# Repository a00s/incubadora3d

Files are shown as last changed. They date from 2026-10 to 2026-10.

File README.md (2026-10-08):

# Mini incubadora CO₂ — v59

Modelo mecânico para impressão 3D, desenvolvido em CadQuery, com porta articulada,
três gavetas removíveis, reservatório de água e compartimentos de CO₂ e eletrônica.
A versão atual completa a rampa a 45° atrás da base da lingueta, incluindo seu lado externo.
As gavetas usam guias abertas e as lâminas são apoiadas somente por baixo.
Vedação, resistência e funcionamento térmico ainda precisam de validação física.

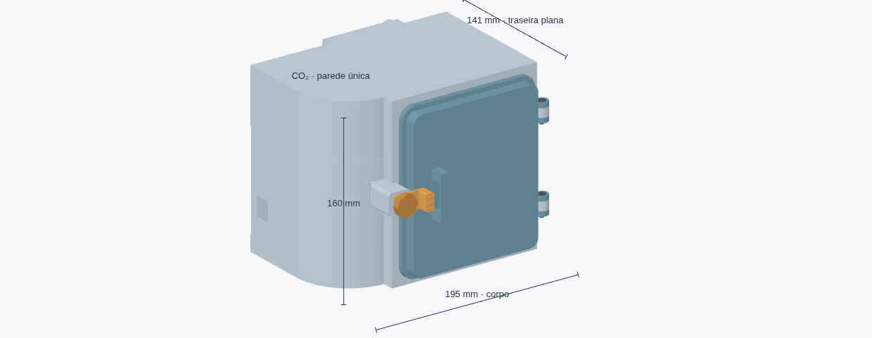
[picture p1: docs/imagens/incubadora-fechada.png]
Incubadora v59 fechada, com porta e fecho central


## Arquivos para visualizar e imprimir

- [Visualizador interativo offline](output/visualizador.html): baixe e abra no navegador.
- [Projeto Creality Print 7.2.1](output/incubadora_CrealityPrint_7.2.1.3mf): 38 peças em 36 bandejas, incluindo molde e contraformas, escala 1:1, sem fatiamento ou G-code.
- [Molde e contraforma do inox](output/v59/ferramental_inox/LEIA_ME.md): macho e duas metades de fechamento, com STL e STEP.
- [STL da carcaça com a traseira na mesa](output/v59/impressao_traseira_na_mesa/corpo_integrado.stl).
- [STL, STEP, amostras e relatórios da v59](output/v59/).
- [Conjunto completo em STEP](output/v59/conjunto.step).
- [Situação técnica e pendências](STATUS.md).

O GitHub não executa o HTML: salve o arquivo localmente para usar os controles.
Os arquivos de versões antigas foram removidos da árvore atual; podem ser recuperados pelo histórico do Git.

## Medidas principais

As medidas estão em milímetros. Largura × altura × profundidade para a câmara e o inox.

| Elemento | Medida |
| --- | --- |
| Carcaça na orientação de montagem, largura × profundidade × altura | 195 × 141 × 160 |
| Carcaça com a traseira na mesa, largura × profundidade da mesa × altura de impressão | 195 × 160 × 141 |
| Câmara rígida interna | 112 × 132 × 111; cantos R6 |
| Caixa inox, dimensão externa de referência | 111 × 131 × 110 |
| Caixa inox, dimensão interna de referência | 110,4 × 130,4 × 109,7 |
| Espessura do inox de referência | 0,3 |
| Gavetas, largura × profundidade × espessura da base | 102,2 × 72 × 3 |
| Passo vertical entre gavetas | 29 |
| Alojamento das lâminas | 76,8 × 26,8; rebaixo de 0,6 |
| Caixinha traseira, largura × altura × profundidade | 70 × 60 × 21 |

A caixa inox e o [molde de referência](output/v59/molde_caixa_inox_referencia.stl)
não constituem um plano de corte de chapa: dobras, raios e acabamento precisam ser
conferidos na fabricação. Os furos de referência do inox alinham as passagens de CO₂ e fios.

## Porta, vedação e acesso

A porta é uma peça rígida, com todo o ressalto interno em V de ponta plana.
O ressalto entra no perfil correspondente do corpo. Uma junta TPU labial
fica encaixada nele; a junta TPU do corpo complementa a vedação.
O manípulo central regula a compressão. A estanqueidade depende do ajuste e de ensaio físico.

Para abrir, afrouxe o manípulo e gire a lingueta central 90° para baixo.
A pega lateral é uma dupla hélice circular real, com duas curvas vistas de frente,
hastes cilíndricas Ø3,2 mm e travessas Ø2,2 mm. Os apoios são curvos e se
alargam gradualmente até a porta, com raio de 1,8 a 4 mm.
A hélice tem raio de 6 mm e uma volta completa ao longo de 36 mm;
o envelope com apoios tem altura de 54 mm, profundidade de 15,2 mm e
projeção de 18,6 mm além da placa. Imprimir com a **frente externa plana na mesa**
e o ressalto interno em V para cima, com suportes externos para a hélice.
O isolamento da porta foi redesenhado para essa posição: 30 canais alongados,
em duas fileiras, com paredes de 2 mm. Os tetos avançam a 45° no sentido +Y
do CAD e fecham pela largura curta de cada canal, com ponte final de 0,4 mm.
A [conferência das rampas](output/v59/door_roof_report.json) e o
[fatiamento de teste deitada](output/v59/door_slice_report.json) estão registrados.
No visualizador, escolha **Impressão da porta · frente para baixo** e mova
**Camada da porta** entre 5,2 e 8 mm para ver os canais fechando.
Os vazados pertencem somente à pega externa: nenhum corte atravessa a porta,
as células de isolamento ou o perímetro de vedação. O canal e as juntas TPU
foram preservados. Ergonomia e estanqueidade dependem de teste físico.
As duas dobradiças usam M4 × 20 escareados, porcas metálicas na porta e buchas de compressão.
Os apoios fixos têm rampas externas a 45° para impressão da carcaça com a traseira na mesa.
Atrás das duas dobradiças e da base da lingueta, as rampas dentro da parede também
fecham a 45°, substituindo os tetos retos sobre as cavidades de isolamento.
A base da lingueta também tem rampa externa, eliminando a face traseira reta que
ainda ficava suspensa. O reforço preserva o volume interno do compartimento de CO₂.

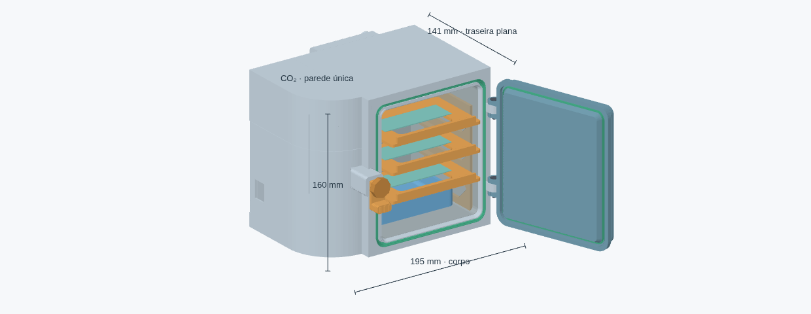
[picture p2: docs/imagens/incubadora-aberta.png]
Porta aberta a 110° e gavetas parcialmente retiradas na v59


O misturador de CO₂ tem teto integrado, com abertura para o sensor.
A tampa lateral removível dá acesso à eletrônica: solte seu M4 × 12 e retire-a para cima.
A entrada de gás recebe mangueira de silicone Ø externo 6,0 em alojamento Ø6,2,
com boca chanfrada Ø6,8 e profundidade de encaixe de 12 mm.
O canal interno de comunicação com a câmara e o furo correspondente no inox têm Ø6,2.
A folga diametral nominal é de 0,2 mm; conferir encaixe e vedação nas amostras OD6.
O canal não bloqueia retorno de umidade.

## Gavetas e lâminas

O suporte removível tem laterais reforçadas e apoios de 6 mm de largura.
As gavetas entram pela frente em guias abertas, com chanfro de entrada de 2 mm
e folga lateral de 0,8 mm por lado. Apoie a gaveta nos dois trilhos e deslize até o batente traseiro.
Não há tampa superior do trilho nem encaixe estreito para alinhar.
Para retirar completamente, puxe a gaveta segurando-a quando ela deixar os apoios.

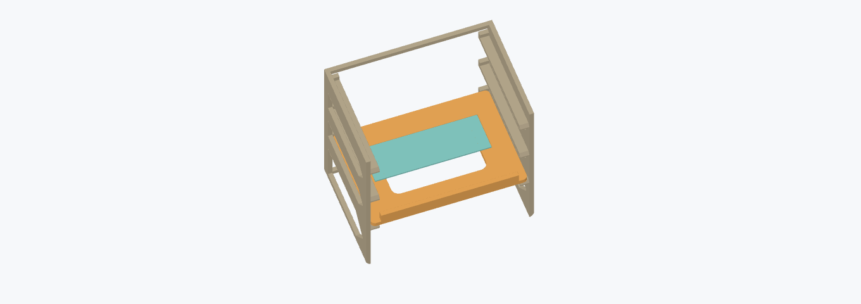
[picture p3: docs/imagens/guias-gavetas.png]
Suporte reforçado com guias abertas e uma gaveta assentada


A lâmina fica num rebaixo de 0,6 mm na própria base. O apoio é somente inferior;
as bordas do rebaixo limitam o deslocamento horizontal. Coloque e retire a lâmina
por cima. Não há presilhas, lingueta ou material sobre sua área.
O alojamento aberto permite levantar a lâmina e não a retém se a gaveta for invertida.

O desenho foi conferido para lâminas de 76 × 26 e 75 × 25, com espessuras de 0,9 a 1,2.
A referência visual mede 76 × 26 × 1. A área central da gaveta permanece vazada.

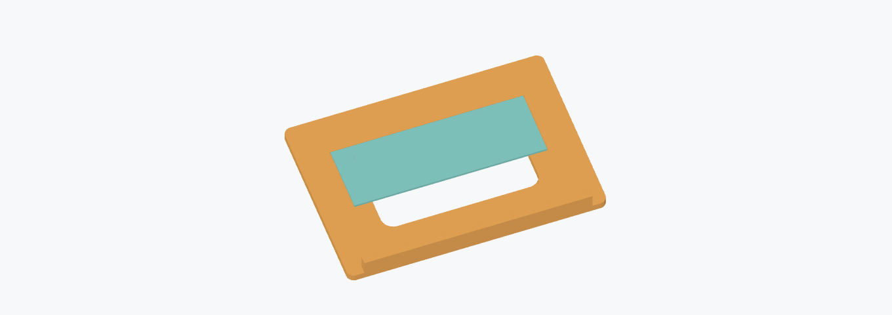
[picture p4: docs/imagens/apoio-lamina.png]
Lâmina apoiada por baixo no rebaixo da gaveta, totalmente livre por cima


## Caixinha traseira e passagens

A caixinha de 70 × 60 × 21 acomoda a sobra dos fios e tem conector lateral Ø8.
As bordas superior e inferior que tocam a incubadora são retas.
A fixação usa dois M4 × 12, com aproximadamente 4 mm de engate no corpo.
Os pilotos são cegos, dentro de apoios maciços Ø16: há 5,6 mm de material atrás
do piloto e 6,25 mm nas laterais. A parede quente de 4 mm permanece contínua sob os apoios.

As passagens de fios usam buchas TPU. Montagem dos fios, compressão das buchas,
retenção dos parafusos e vedação precisam ser conferidas com os componentes reais.
Teste primeiro a [amostra da fixação M4](output/v59/amostra_caixinha_fixacao_M4.stl).

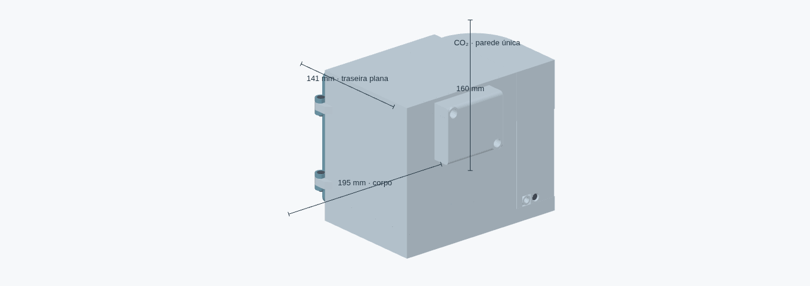
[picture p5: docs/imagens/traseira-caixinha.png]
Vista traseira com caixinha de fios e fixações da v59


## Impressão

A orientação da **carcaça** é com a traseira apoiada na mesa.
Use o STL indicado acima ou a bandeja da carcaça no projeto Creality Print.
A camada de isolamento tem 23 cavidades alongadas, faces de 2 mm e fechamento a 45°,
com ponte final nominal de 0,4 mm. A parede da câmara tem 4 mm.
Os furos e as fixações mantêm reforços locais maciços.

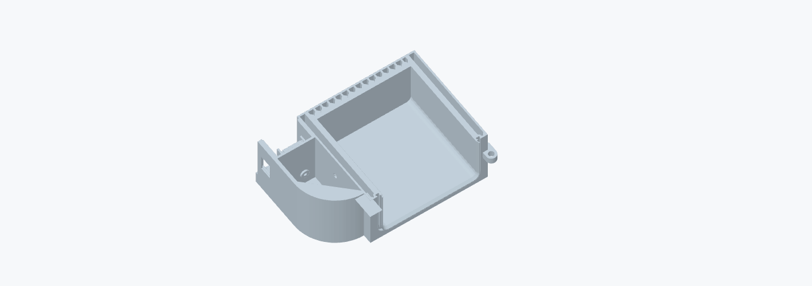
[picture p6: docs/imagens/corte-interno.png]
Corte da carcaça mostrando cavidades alongadas e canais na parede traseira


Materiais previstos no desenho: PC para peças rígidas, TPU 95A para vedações e
inox de 0,3 mm para o revestimento. O 3MF referencia os perfis genéricos
PC/TPU e o processo padrão da K1C com bico de 0,4 mm, sem configurações
personalizadas de filamento ou velocidades por peça. Selecione sua configuração
padrão no Creality Print e ajuste a temperatura conforme o filamento utilizado.
As juntas estão atribuídas ao TPU; imprima cada bandeja com o material correspondente.
O projeto não contém um processo de impressão validado.
STL e STEP contêm geometria; as configurações ficam no projeto 3MF.

Antes de imprimir, confira na prévia de camadas:

- Ausência de suporte preso dentro das cavidades fechadas da carcaça.
- Perímetros e continuidade de material ao redor de furos e vedações.
- Pontes, encaixes, roscas e pequenos detalhes com os parâmetros escolhidos.
- Orientação da porta: ainda não foi definida nem validada.

O suporte das gavetas foi desenhado para a traseira na mesa; as janelas fecham a 45°.
As gavetas têm base plana. As orientações das demais peças no projeto devem ser revisadas.
Imprima as amostras de encaixe e vedação antes de comprometer a carcaça inteira.

## Visualizador

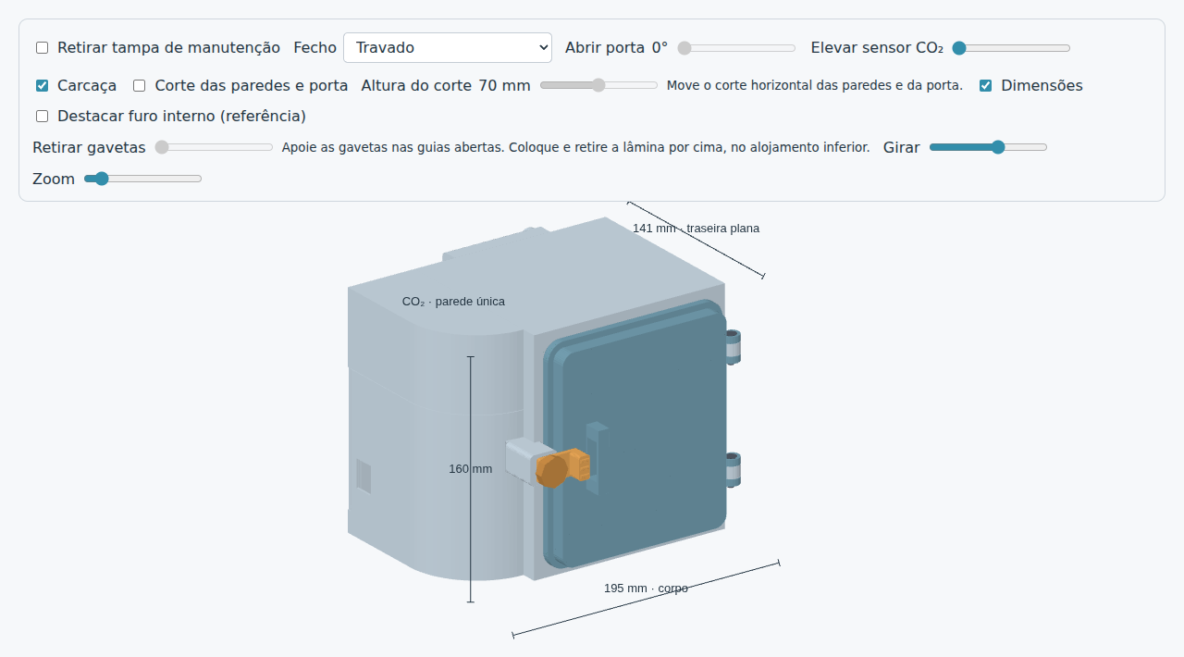
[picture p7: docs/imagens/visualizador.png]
Controles atuais do visualizador da v59


- Arraste o modelo para girar e use **Zoom** para aproximar.
- Selecione **Fecho → Afrouxado e girado 90°** para abrir a porta.
- A retirada das gavetas é liberada no visualizador a partir de 90° de abertura.
- Use **Corte das paredes e porta** e **Altura do corte** para inspecionar as cavidades.
- Em **Peças**, marque componentes ou use **Isolar**.

Os controles mostram a geometria; não substituem testes físicos.

## Gerar os arquivos

Na pasta do repositório:

```bash
python3 -m venv .venv
.venv/bin/python -m pip install -r requirements.txt
.venv/bin/python cad/model.py
.venv/bin/python cad/check_k1c.py
.venv/bin/python cad/build_viewer.py
.venv/bin/python cad/build_creality_project.py --version v59
.venv/bin/python cad/check_creality_project.py --version v59
```

O gerador confere sólidos, interferências e movimentos específicos da porta,
gavetas e lâminas. Os testes adicionais de movimento/roscas são opcionais:

```bash
.venv/bin/python cad/model.py --check-movements
```

Para servir o visualizador na rede local:

```bash
mkdir -p /tmp/incubadora3d-viewer
cp output/visualizador.html /tmp/incubadora3d-viewer/index.html
python3 -m http.server 8081 --bind 0.0.0.0 --directory /tmp/incubadora3d-viewer
```

Acesse `http://IP_DO_SERVIDOR:8081/` com a porta acessível na rede.

## Validação disponível

A v59 passou em 60 pares rígidos sem colisões. O projeto contém 36 bandejas em escala 1:1;
as malhas cabem na K1C com margem de 5 mm. A leitura nativa do Creality Print 7.2.1
terminou com 36 malhas manifold. Gavetas foram conferidas em sete posições de extração;
a área acima das lâminas está livre em um envelope vertical contínuo de 40 mm.

Relatórios: [tetos dos apoios](output/v59/internal_mount_roof_report.json),
[geometria e colisões](output/v59/clash_report.json),
[gavetas e lâminas](output/v59/tray_retention_report.json) e
[projeto Creality](output/v59/projeto_creality_verificacao.json).
Não há fatiamento, ensaio de estanqueidade ou validação operacional.

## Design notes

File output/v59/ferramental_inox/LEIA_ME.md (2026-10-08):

# Molde e contraforma para inox de 0,3 mm

O macho reproduz o interior do revestimento existente e é maciço no CAD.
As contraformas têm paredes de 24 mm, nervuras externas de 12 mm e fechamento
traseiro de 12 mm para apoiar o fundo e travar as laterais. As duas contraformas
fecham por cima e por baixo dele, apoiando os quatro cantos longitudinais.
A cavidade reserva 0,3 mm para a chapa e mais 0,15 mm por face para ajuste.
Raio do macho: 5,2 mm; raio da cavidade: 5,65 mm; comprimento útil: 109,7 mm.

## Arquivos para imprimir

- [Molde interno — macho](molde_caixa_inox_referencia.stl).
- [Contraforma inferior](contraforma_inox_inferior.stl).
- [Contraforma superior](contraforma_inox_superior.stl).

Há um STEP de cada peça nesta pasta para usinagem ou ajustes.
Os STL já estão com uma extremidade plana na mesa, Z mínimo zero.
As três peças cabem individualmente na K1C com margem de 5 mm.
O projeto completo `output/incubadora_CrealityPrint_7.2.1.3mf` inclui todas
as ferramentas: macho na bandeja 10, contraforma inferior na 35 e superior na 36.
As duas últimas compartilham espaço com amostras pequenas de PC, sem sobreposição.
O projeto possui 38 peças em 36 bandejas.
A escolha de paredes, preenchimento e material deve considerar o esforço aplicado;
a resistência das ferramentas impressas ainda não foi ensaiada.

## Uso

1. Pré-dobre as laterais da chapa ao redor do macho. O ferramental serve para
   acertar as dobras e os raios de uma chapa já pré-formada.
2. Apoie a contraforma inferior numa placa plana e rígida. Coloque o macho
   com o inox dentro dela e encaixe a contraforma superior.
3. Alinhe os quatro furos Ø6,6 mm. Eles aceitam hastes ou parafusos M6;
   a distância total entre faces externas fechadas é 179,3 mm.
   Se usar parafusos, reserve comprimento adicional para placas, arruelas e porcas.
4. Distribua o aperto com outra placa rígida por cima e feche gradualmente,
   alternando os lados. As faces de encontro das contraformas limitam o fechamento.
5. Abra as metades e retire o macho pela frente. Faça primeiro um ensaio com
   retalho do mesmo inox para avaliar acabamento, folga e retorno elástico.

## Marcação e furação do inox

As guias passantes da contraforma têm Ø2,5 mm. No macho, os mesmos eixos têm
pilotos cegos Ø2,5 × 3 mm. Use-os com o ferramental **fechado**, para marcar
ou iniciar os furos sem deslocar a chapa. Retire a chapa para ampliar ao diâmetro
final e remover rebarbas; não perfure o macho além dos pilotos cegos.

| Furo | Centro no CAD (mm) | Direção | Diâmetro final |
| --- | --- | --- | --- |
| Entrada CO₂ | X=4,5; Y=60; Z=34 | lateral, eixo X | 6,2 mm |
| Acesso lateral | X=4,5; Y=90; Z=127,5 | lateral, eixo X | 14 mm |
| Acesso traseiro | X=60; Y=110; Z=116 | fundo, eixo Y | 14 mm |

Os centros correspondem às três aberturas do revestimento atual. Os furos
Ø6,6 mm das abas são de alinhamento M6 e não são furos a transferir ao inox.

O conjunto conforma as quatro dobras ao longo da profundidade da caixa.
**O fundo, os recortes e as emendas não são formados por essas peças.**
O revestimento CAD continua sendo uma referência de montagem, não um desenho
planificado de corte e solda. A folga adicional não foi compensada por simulação
de retorno elástico, nem foi calculada uma força de prensa.

## Visualizador

Abra [visualizador.html](../../visualizador.html) e escolha
**Visualizar → Molde e contraforma do inox**. O controle **Abrir contraforma**
afasta cada metade de 0 a 80 mm. Na lista de peças é possível ocultar o macho,
o inox ou cada metade para inspecionar o encaixe. A opção **Destacar centros
dos furos no ferramental** mostra as posições e os diâmetros finais no inox.

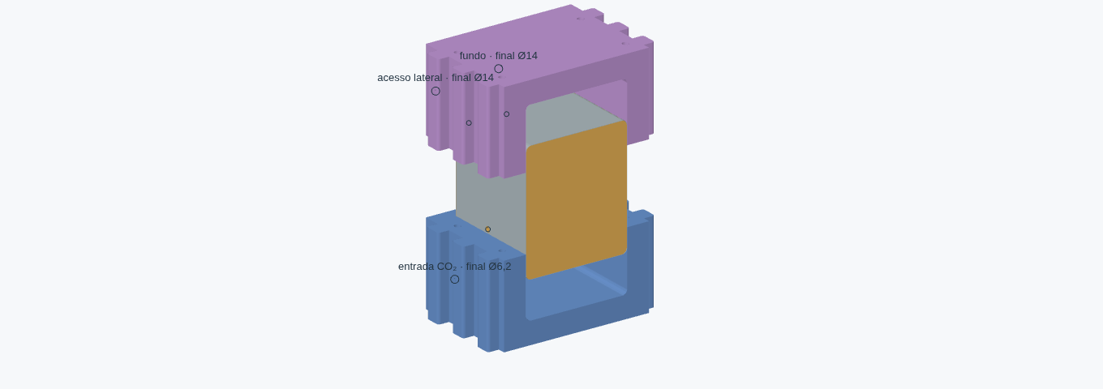
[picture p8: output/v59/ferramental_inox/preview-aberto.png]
Conjunto aberto


## Regeneração e verificações

Execute `python cad/forming_tools.py` no ambiente com CadQuery e depois
`python cad/build_viewer.py`. O gerador principal `cad/model.py` também exporta
o ferramental. `python cad/pack_forming_tools.py` atualiza o ferramental
no 3MF salvo pelo usuário, preservando suas configurações. Execute
`python cad/check_complete_project.py` para verificar esse arquivo.
[verificacao.json](verificacao.json) registra os limites e as
verificações de sólidos, interferências e abertura.

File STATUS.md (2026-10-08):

# Estado atual — v59

Arquivos atuais em [output/v59](output/v59/), com visualizador e projeto Creality Print
na raiz de `output/`. A árvore atual mantém somente esta versão; revisões anteriores
estão no histórico do Git. O [manual ilustrado](README.md) descreve o desenho atual.

## Configuração

- Carcaça integrada, impressão com traseira Y125 na mesa, construção na direção −Y.
- Câmara 112 × 132 × 111 mm; parede quente de 4 mm; inox de referência 0,3 mm.
- Isolamento com 23 cavidades alongadas, fechamentos a 45° e ponte nominal de 0,4 mm.
- Porta monolítica com ressalto inteiro em V, junta TPU labial retida e junta secundária no corpo.
- Pega externa em dupla hélice circular real, duas curvas, raio de 6 mm,
  volta completa em 36 mm, hastes Ø3,2 mm e travessas Ø2,2 mm.
  Envelope: altura 54 mm, profundidade 15,2 mm e projeção 18,6 mm além da placa.
  Apoios curvos alargam de R1,8 para R4 junto à porta.
  Frente externa plana Y=-16 na mesa, ressalto V para cima. Isolamento redesenhado: 30 canais em duas fileiras, paredes e nervura central de 2 mm, tetos de 45° fechando em +Y com ponte final de 0,4 mm. Revisar suportes externos na hélice. Nenhum corte na porta ou canal TPU.
  O 3MF salvo pelo usuário recebeu a porta DNA, preservando configurações e demais malhas; validação física de gás pendente.
- Fecho central; lingueta liberando a abertura quando girada 90° após afrouxar o manípulo.
- Duas dobradiças M4 × 20 escareadas, porcas metálicas na porta e apoios externos a 45°.
- Rampas internas a 45° nas cavidades atrás das dobradiças e da base da lingueta.
- Rampa externa da lingueta elimina a face plana remanescente; cavidade CO₂ preservada.
- Auditoria final dos apoios inclui ambos os lados da base da lingueta e das dobradiças.
- Suporte removível reforçado, guias abertas, apoio de 6 mm e folga lateral de 0,8 mm por lado.
- Gavetas com base de 3 mm e rebaixo de lâmina de 0,6 mm; nenhum elemento sobre a lâmina.
- Lâminas conferidas: 76 × 26 e 75 × 25 mm, espessuras 0,9, 1 e 1,2 mm.
- Caixinha traseira 70 × 60 × 21 mm, dois M4 × 12 com engate de 4 mm em apoios cegos maciços.
- Mangueira CO₂ Ø6 mm: entrada e passagem interna Ø6,2 mm, boca Ø6,8 mm e furo do inox Ø6,2 mm; encaixe e vedação física pendentes.
- Misturador CO₂ com teto integrado e abertura do sensor; eletrônica acessível pela tampa lateral.

- Ferramental inox: macho maciço com pilotos cegos e contraformas superior/inferior de 24 mm, nervuras de 12 mm e apoio traseiro. Guias Ø2,5 mm para os três furos do inox; chapa 0,3 mm + folga 0,15 mm por face. Modo próprio no visualizador.

## Validação

- Porta deitada: todas as cavidades CAD e tetos centrais do STL auditados para +Y; rampas de 45°, ponte final ≤0,4 mm e fechamento transversal conferidos. Fatiamento da bandeja 2 no Creality Print 7.2.1: saída 0, sem avisos, altura 19 mm e 99 camadas. Teste separado com brim de 5 mm e suporte a partir da mesa; 18.745 pontos médios de segmentos de suporte conferidos, nenhum dentro das cavidades. Sem ensaio físico.

- Ferramental: três sólidos válidos, sem interseção com o inox; abertura em Z de 0 a 80 mm conferida e visualizador testado em WebGL. Força e retorno elástico pendentes de ensaio físico.
- Corpo único e peças válidas; 59 pares rígidos sem colisão após remover o puxador.
- Faces finais dos tetos auditadas nas duas dobradiças e no fecho: rampas a 45°, pontes restantes ≤0,4 mm.
- Amostra da dobradiça recortada da parede oca real, com ambas as rampas.
- Porta, lingueta, inserção do inox e retirada da caixinha conferidas geometricamente.
- Extração das gavetas a 0, 5, 15, 30, 50, 72 e 80 mm com porta a 110°.
- Apoio inferior e limites laterais das lâminas conferidos; envelope superior de 40 mm livre.
- 38 peças no 3MF completo, compatíveis com a K1C e margem de 5 mm. Macho na bandeja 10 e contraformas nas 35/36, compartilhadas com amostras PC; pelo menos 5 mm entre peças.
- 3MF principal e da v59 atualizados com a porta DNA; ZIP/XML, malha fechada, escala 1:1 e limites K1C conferidos. Abertura nativa e fatiamento da atualização pendentes.
- 3MF com 38 peças em 36 bandejas em escala 1:1, sem G-code; leitura atual das 38 malhas manifold no CLI Creality Print 7.2.1, saída 0, com `--allow-newer-file` para preservar o projeto principal salvo pelo usuário em 7.3. Sem fatiamento.
- Visualizador regenerado com passagem Ø6,2; teste WebGL e controles anterior ao ajuste CO₂. Imagens gerais do manual correspondem à v59.

Relatórios em [output/v59](output/v59/). Os ensaios amplos de roscas/movimento continuam
opcionais em `cad/model.py --check-movements`. TPU com compressão intencional é excluído
da auditoria rígida. As verificações não simulam deformação, resistência ou vazamento.

## Pendências

- 3MF com referências aos perfis genéricos PC/TPU e processo padrão; sem ajustes personalizados de filamento ou velocidades. Selecionar o perfil padrão e ajustar a temperatura no fatiador; sem validação física.
- Fatiamento, calibração dos parâmetros de PC/TPU e ausência de suporte preso nas cavidades fechadas.
- Impressão física da porta com a frente na mesa, suportes externos e testes dos encaixes, roscas e guias.
- Estanqueidade da porta, passagens de fios, conexão de gás e superfícies impressas.
- Ajuste e fabricação da caixa inox; o modelo de referência não é plano de corte de chapa.
- Medidas finais dos conectores, posicionamento do aquecedor, fios e suporte do sensor.
- Desempenho térmico/CO₂, condensação, limpeza e funcionamento operacional.

O alojamento das lâminas é aberto: limita deslizamento enquanto assentadas, mas permite
retirada vertical e não as segura em uma gaveta invertida. Sem validação física ou operacional.

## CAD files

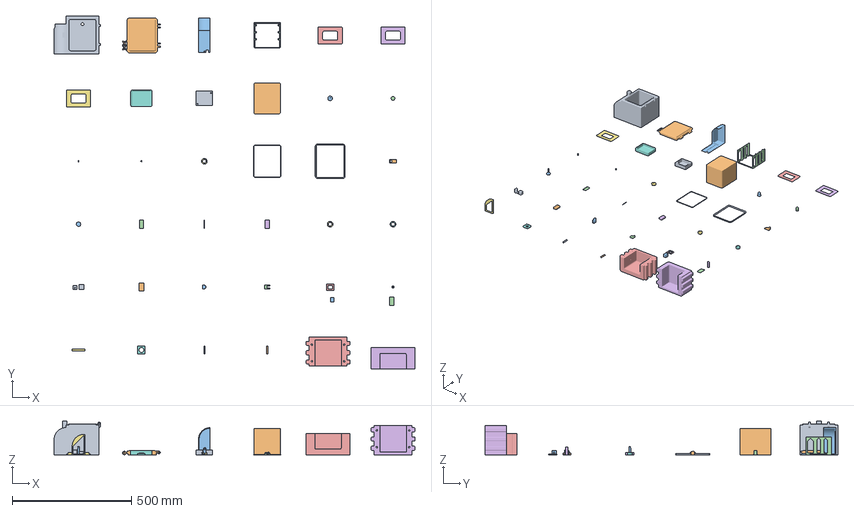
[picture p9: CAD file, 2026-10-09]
output/incubadora_CrealityPrint_7.2.1.3mf
1514.0 x 1481.5 x 141.0 mm
corpo_integrado
porta_articulada
tampa_manutencao_CO2_eletronica
suporte_gavetas_removivel
bandeja_1
bandeja_2
bandeja_3
reservatorio_agua
caixinha_encaixe_aquecedor
molde_caixa_inox_referencia
TPU_passagem_aquecedor
TPU_passagem_sensor
bucha_dobradica_102
bucha_dobradica_22
bucha_sensor_TPU
junta_V_porta_TPU
junta_porta
lingueta_fecho_70
manipulo_fecho_70
amostra_V_assento_corpo
amostra_V_porta_TPU
amostra_V_porta_rigida
amostra_bucha_sensor_TPU_15.3
amostra_bucha_sensor_TPU_15.5
amostra_caixinha_fixacao_M4
amostra_canal_rigido
amostra_dobradica_base_M4x20
amostra_dobradica_porta_M4x20
amostra_encaixe_RJ45
amostra_entrada_CO2_mangueira_OD6
amostra_fechamento_CO2_45graus_PC
amostra_furo_sensor_integrado
amostra_junta_TPU
amostra_junta_TPU_labios_0p8
amostra_passagem_interna_CO2_OD6
amostra_pressao_junta
contraforma_inox_inferior
contraforma_inox_superior

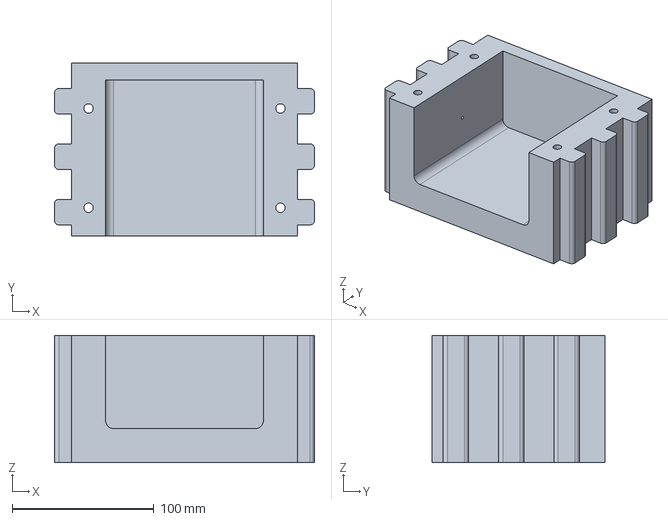
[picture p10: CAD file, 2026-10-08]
output/v59/ferramental_inox/contraforma_inox_inferior.step
183.3 x 122.2 x 89.7 mm

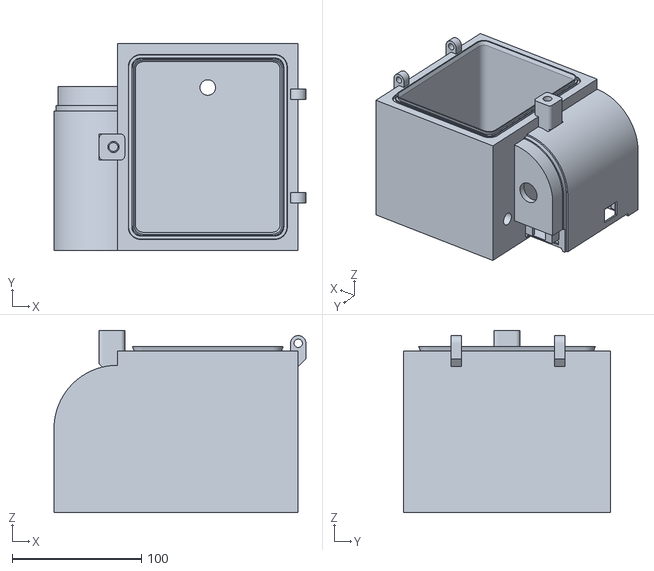
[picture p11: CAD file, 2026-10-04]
output/v59/impressao_traseira_na_mesa/corpo_integrado.stl
195.0 x 160.0 x 141.0

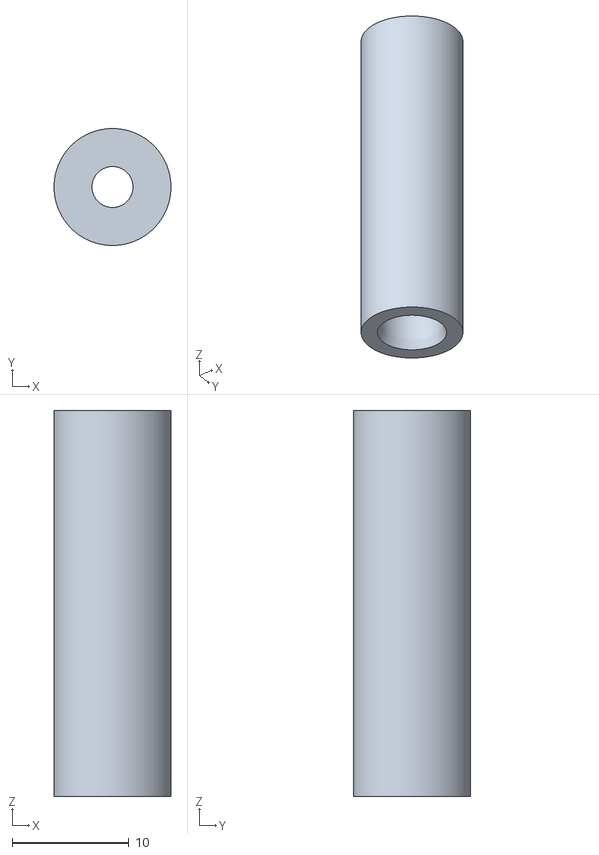
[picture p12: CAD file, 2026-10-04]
output/v59/k1c_posicionados/amostra_entrada_CO2_mangueira_OD6.stl
10.0 x 10.00 x 33.0

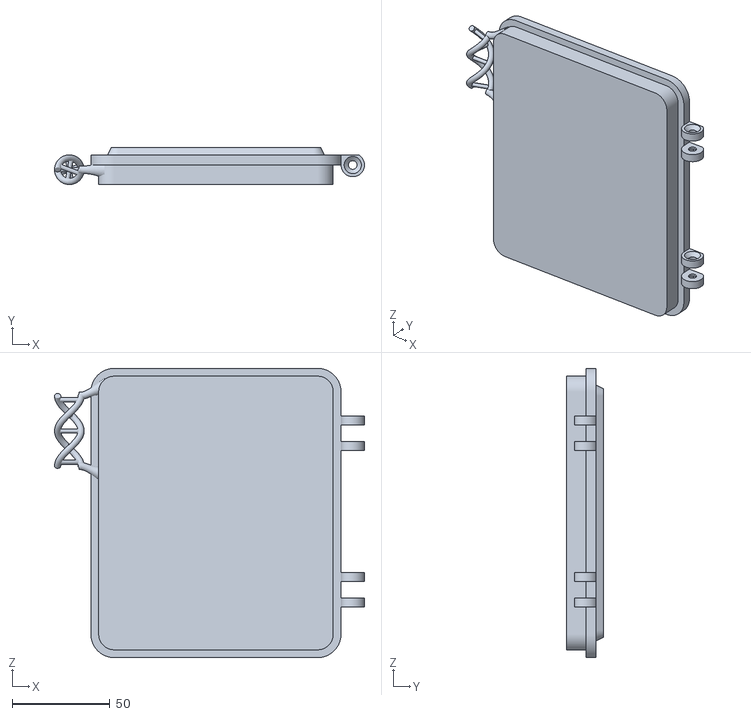
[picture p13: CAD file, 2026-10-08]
output/v59/porta_articulada.stl
158.6 x 19.0 x 148.0

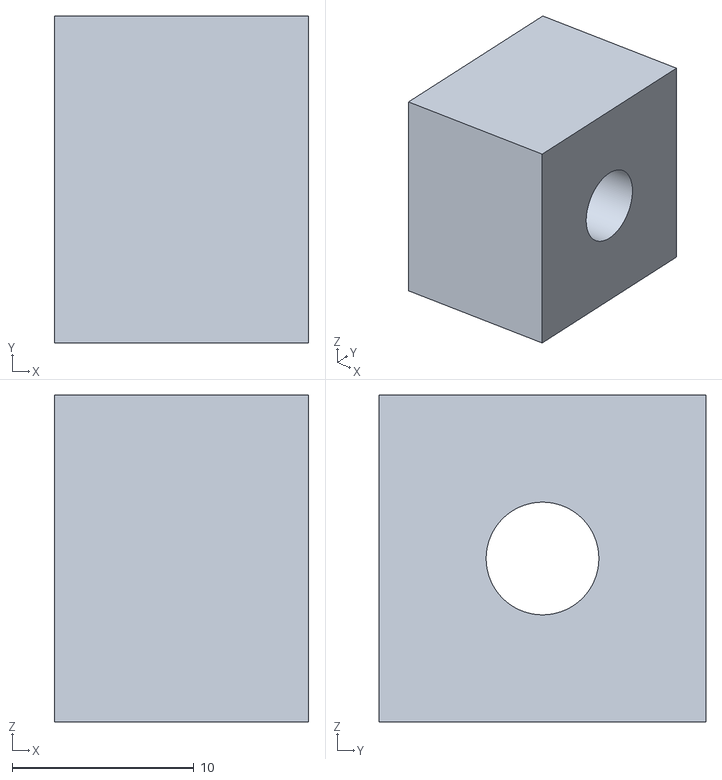
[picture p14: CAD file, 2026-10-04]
output/v59/k1c_posicionados/amostra_passagem_interna_CO2_OD6.stl
14.0 x 18.0 x 18.0

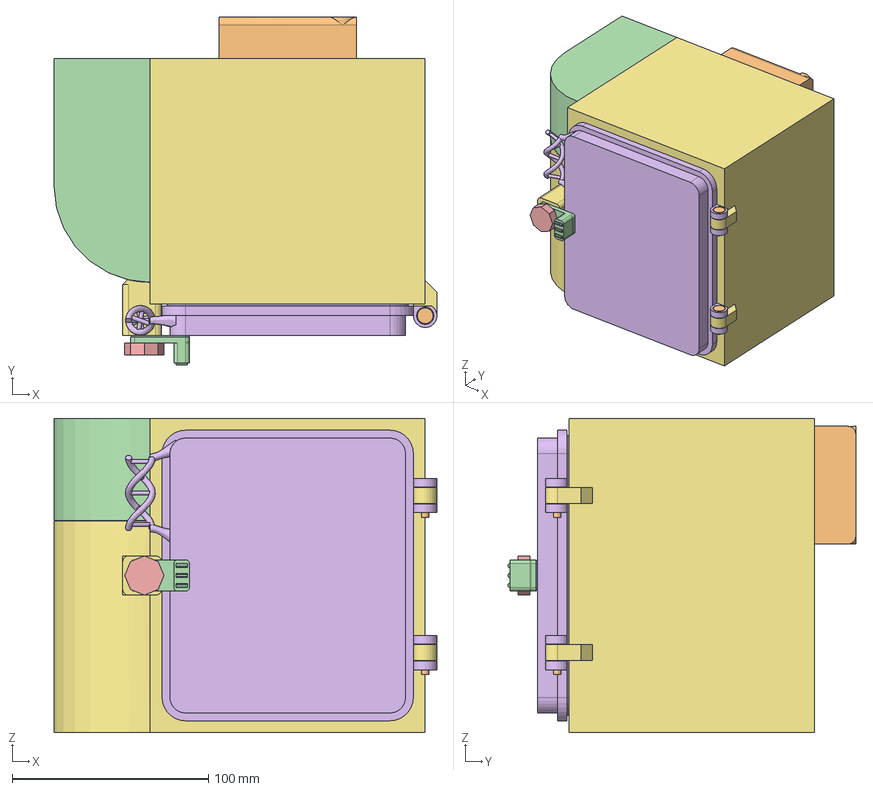
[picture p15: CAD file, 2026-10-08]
output/v59/conjunto.step
195.0 x 177.0 x 160.0 mm

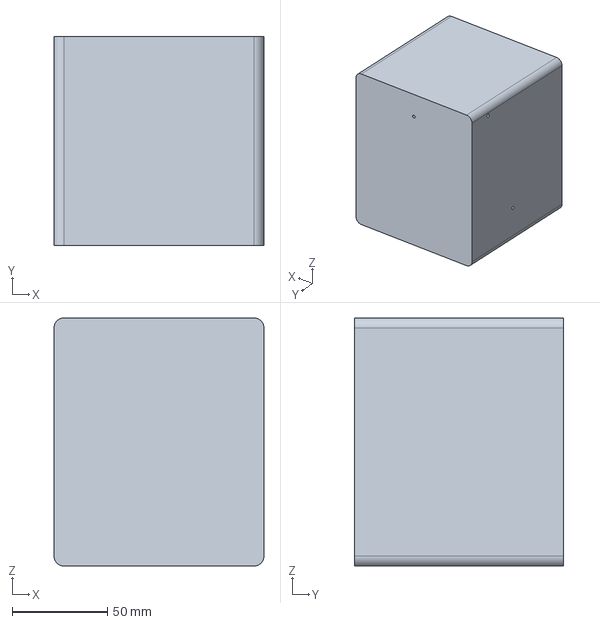
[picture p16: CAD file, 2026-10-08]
output/v59/ferramental_inox/molde_caixa_inox_referencia.step
110.4 x 109.7 x 130.4 mm

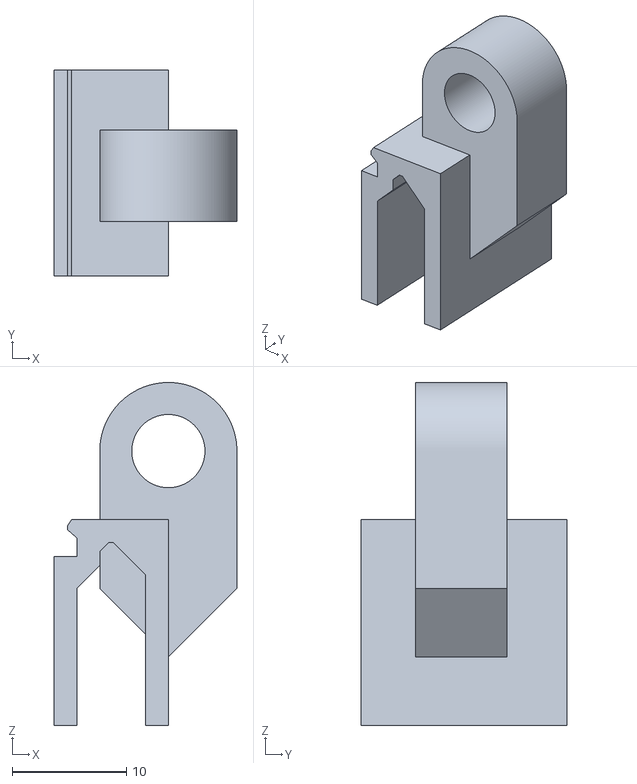
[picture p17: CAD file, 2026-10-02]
output/v59/k1c_posicionados/amostra_dobradica_base_M4x20.stl
16.0 x 18.0 x 30.0

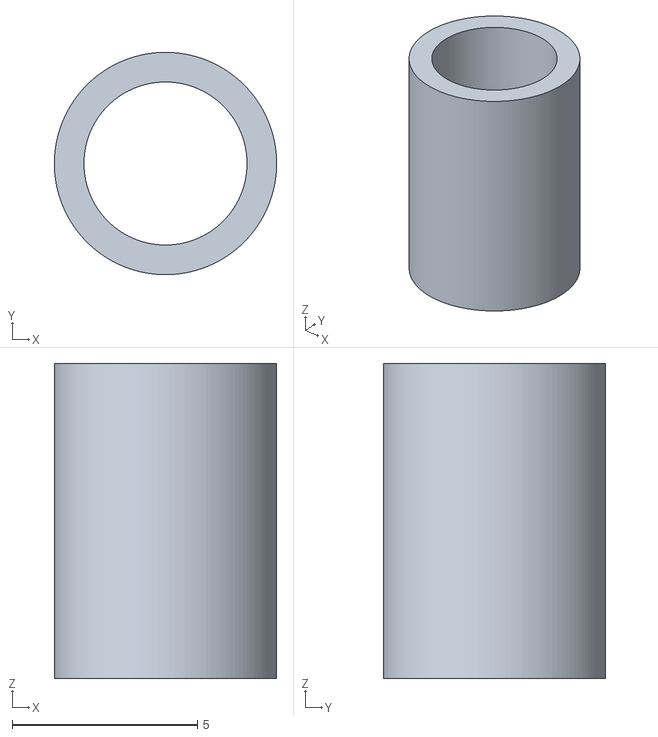
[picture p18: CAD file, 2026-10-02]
output/v59/k1c_posicionados/bucha_dobradica_22.stl
6.00 x 6.00 x 8.50

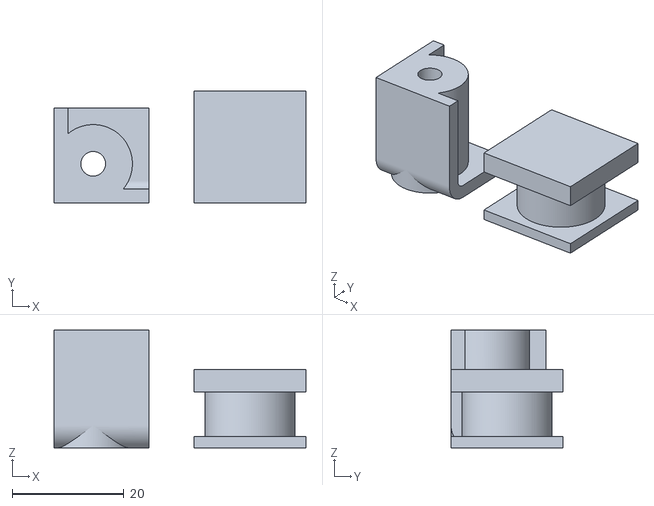
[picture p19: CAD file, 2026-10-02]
output/v59/k1c_posicionados/amostra_caixinha_fixacao_M4.stl
45.0 x 20.0 x 21.0

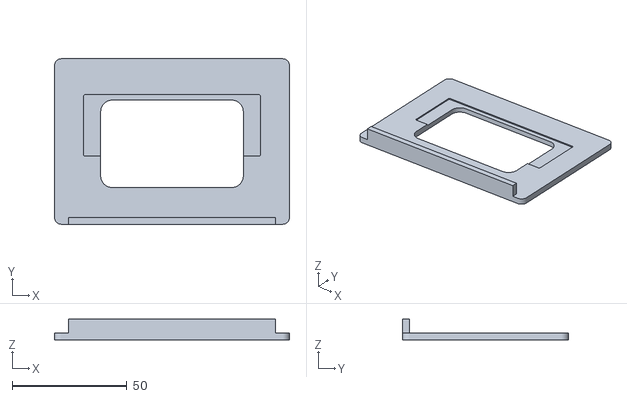
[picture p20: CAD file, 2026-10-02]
output/v59/k1c_posicionados/bandeja_2.stl
102.2 x 72.0 x 9.00

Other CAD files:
output/v59/ferramental_inox/contraforma_inox_superior.step
output/v59/incubadora_v59_CrealityPrint_7.2.1.3mf
output/v59/k1c_posicionados/corpo_integrado.stl
output/v59/molde_caixa_inox_referencia.step
output/v59/corpo_integrado.stl
output/v59/amostra_passagem_interna_CO2_OD6.stl
output/v59/TPU_passagem_aquecedor.stl
output/v59/TPU_passagem_sensor.stl
output/v59/amostra_V_assento_corpo.stl
output/v59/amostra_V_porta_TPU.stl
output/v59/amostra_V_porta_rigida.stl
output/v59/amostra_bucha_sensor_TPU_15.3.stl
output/v59/amostra_bucha_sensor_TPU_15.5.stl
output/v59/amostra_caixinha_fixacao_M4.stl
output/v59/amostra_canal_rigido.stl
output/v59/amostra_dobradica_base_M4x20.stl
output/v59/amostra_dobradica_porta_M4x20.stl
output/v59/amostra_encaixe_RJ45.stl
output/v59/amostra_entrada_CO2_mangueira_OD6.stl
output/v59/amostra_fechamento_CO2_45graus_PC.stl
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

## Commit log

2026-09-21 Atualiza design da incubadora v28 e visualizador
    [TPU_passagem_aquecedor.stl, TPU_passagem_sensor.stl, amostra_bucha_sensor_TPU_15.3.stl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]
2026-09-21 Fecha cantos frontais e adiciona corte ajustável no visualizador v29
    [TPU_passagem_aquecedor.stl, TPU_passagem_sensor.stl, amostra_bucha_sensor_TPU_15.3.stl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]
2026-09-21 Limita rosca do manípulo à ponta junto à porca
    [TPU_passagem_aquecedor.stl, TPU_passagem_sensor.stl, amostra_bucha_sensor_TPU_15.3.stl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]
2026-09-21 Integra roscas do fecho e tampa CO2 à base e amplia haste lisa
    [TPU_passagem_aquecedor.stl, TPU_passagem_sensor.stl, amostra_bucha_sensor_TPU_15.3.stl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]
2026-09-21 Nivela traseira e adiciona pega e contato chanfrado na lingueta
    [TPU_passagem_aquecedor.stl, TPU_passagem_sensor.stl, amostra_bucha_sensor_TPU_15.3.stl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]
2026-10-02 Atualiza incubadora ate v57 com vedacao e gavetas abertas
    [TPU_passagem_aquecedor.stl, TPU_passagem_sensor.stl, amostra_U_borda_corpo.stl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]
2026-10-02 Atualiza manual ilustrado e mantem somente a versao v57
    [TPU_passagem_aquecedor.stl, TPU_passagem_aquecedor_A.stl, TPU_passagem_aquecedor_B.stl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]
2026-10-02 Corrige tetos internos das dobradicas e do fecho na v58
    [TPU_passagem_aquecedor.stl, TPU_passagem_sensor.stl, amostra_V_assento_corpo.stl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]
2026-10-02 Corrige teto externo da base da lingueta com rampa a 45 graus (v59)
    [TPU_passagem_aquecedor.stl, TPU_passagem_sensor.stl, amostra_V_assento_corpo.stl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]
2026-10-03 Configura perfil CC3D PC conforme etiqueta do rolo
    [incubadora_CrealityPrint_7.2.1.3mf, incubadora_v59_CrealityPrint_7.2.1.3mf]
2026-10-04 Ajusta passagens CO2 para tubo de 6 mm e remove perfil personalizado
    [amostra_entrada_CO2_mangueira_OD5p8.stl, amostra_entrada_CO2_mangueira_OD6.stl, amostra_passagem_interna_CO2_OD5p8.stl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]
2026-10-07 Redesenha puxador da porta com dupla helice de DNA e apoios curvos
    [conjunto.step, porta_articulada.stl]
2026-10-08 Atualiza projetos 3MF com porta de puxador DNA
    [incubadora_CrealityPrint_7.2.1.3mf, incubadora_v59_CrealityPrint_7.2.1.3mf]
2026-10-08 Adiciona contraforma bipartida do inox e modo de ferramental no visualizador
    [contraforma_inox_inferior.step, contraforma_inox_inferior.stl, contraforma_inox_superior.step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]
2026-10-08 Reforca ferramental inox, adiciona guias dos furos e inclui contraformas no 3MF completo
    [contraforma_inox_inferior.step, contraforma_inox_inferior.stl, contraforma_inox_superior.step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]
2026-10-08 Corrige orientacao da porta nos projetos 3MF com face externa na mesa
    [incubadora_CrealityPrint_7.2.1.3mf, incubadora_v59_CrealityPrint_7.2.1.3mf]
2026-10-08 Orienta porta em pe conforme rampas internas e valida fatiamento
    [incubadora_CrealityPrint_7.2.1.3mf, incubadora_v59_CrealityPrint_7.2.1.3mf]
2026-10-08 Redesenha canais internos da porta para imprimir com a frente na mesa
    [conjunto.step, incubadora_CrealityPrint_7.2.1.3mf, incubadora_v59_CrealityPrint_7.2.1.3mf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]
2026-10-11 Adiciona fundo interno de 5 mm para conter laterais do inox
2026-10-11 Adiciona moldura frontal removível para apoio e limpeza do inox
2026-10-11 Alarga apoios das gavetas de 6 para 10 mm por lado
2026-10-11 Simplifica centro do suporte e flexibiliza bucha TPU do sensor
2026-10-12 Cria rolhas TPU labiais bipartidas para fios do aquecedor e sensor
2026-10-12 Amplia furo lateral do plugue do aquecedor para 10,68 mm
2026-10-12 Ajusta bucha do sensor para TPU 85A e elimina labios suspensos
2026-10-14 Adapta junta removivel da porta e rolhas para eSUN TPU-LW
2026-10-14 Aumenta junta da porta para tubo oco com lado da dobradica mais baixo
2026-10-15 Add Arduino build workflow and refresh incubator UI
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2026-10-15 Reduz bulbo junto a dobradica e ajusta TPU-LW para 270C
2026-10-15 Migra todas as vedacoes e amostras TPU para eSUN TPU-LW
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2026-10-15 Restore animated indicators and remove stale sensor check
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2026-10-15 Record fan activation and updated CO2 loss rate
2026-10-15 Tighten heater cycling near 37C and record baseline
2026-10-15 Record preliminary loose sensor-ring leak sample
2026-10-15 Refine loose sensor-ring leak comparison
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2026-10-15 Adiciona bulbo oco inferior a bucha CO2 conforme sensor medido
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2026-10-15 Aperta canais dos tres fios do sensor para TPU-LW
2026-10-15 Configura rolha dos tres fios com 30% de preenchimento giroidal
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2026-10-15 Record CO2 decay after water and heat changes
2026-10-15 Redesenha rolha de tres fios como berco com labios e tampa de compressao
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2026-10-15 Alterna painel com gráfico e ajusta doses de CO2
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2026-10-15 Tighten incubator temperature control band
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2026-10-15 Adapta rolha do aquecedor para berço e tampa em TPU-LW
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2026-10-15 Record repeat heater stability run
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2026-10-15 Record another stabilized temperature window
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2026-10-15 Record continuing locked sensor drift
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2026-10-15 Record CO2 sensor range mismatch in project schema
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2026-10-15 Record continuing MH-Z16 drift sample
2026-10-15 Summarize long locked sensor drift window
2026-10-15 Extend locked sensor drift summary
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2026-10-15 Update five minute locked sensor drift summary
2026-10-15 Extend locked sensor drift record
2026-10-15 Document valid UART frames during CO2 safety lock
2026-10-15 Record twelve minute CO2 sensor drift window
2026-10-15 Extend sensor drift trend toward 12k ppm
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2026-10-15 Extend sensor drift observation to 19 minutes
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2026-10-15 Fail safe on heater temperature faults
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2026-10-15 Allow CO2 refill while chamber is losing gas
2026-10-15 Calibrate CO2 valve with a short first pulse
2026-10-16 Tighten CO2 refill threshold and startup delay
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2026-10-16 Make CO2 startup dosing safer and track chamber lag
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2026-10-17 Show CO2 lock and clear with heater triple click
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2026-10-22 Read chamber DS18B20 on D4 with asynchronous CRC-checked conversions
2026-10-22 Adapta passagem lateral para cabo único em TPU 85A
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2026-10-22 Reorganiza temperaturas e taxa de CO2 no visor
2026-10-22 Destaca CO2 e temperatura com numeros do mesmo tamanho
2026-10-22 Revert "Destaca CO2 e temperatura com numeros do mesmo tamanho"
    This reverts commit 904975e542a08f9c2b23586aa197eebf0e1d8c7d.
2026-10-22 Destaca temperatura da câmara e controle de CO2 no visor
2026-10-22 Exibe estimativa de perda de CO2 em cm3 por hora
2026-10-22 Simplifica controles do visor com ícones de atividade
2026-10-22 Mantém tendência de CO2 e adiciona perda acima dos ícones no rodapé
2026-10-22 Baixa tendência de CO2 e separa temperaturas com divisória
2026-10-22 Corrige estimativa de perda com confiança por amostras e tela de alerta
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2026-10-22 Usa duração real entre doses sem mínimo fixo para medir perda
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2026-10-23 Exibe porta apenas após inferência de abertura e corrige lado do ícone
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2026-10-27 Corrige potência proporcional do PID e antecipa frenagem térmica
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2026-11-05 Valida CO2 em 2011 cenários e reduz sondas e progressão de doses
2026-11-05 Corrige conservação no simulador de CO2 e modela duas câmaras
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2026-11-06 Reavalia piso de CO2 com atraso de resposta e aumento de vazão
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2026-11-06 Test requested doubling calibration without deploying failed controller
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
